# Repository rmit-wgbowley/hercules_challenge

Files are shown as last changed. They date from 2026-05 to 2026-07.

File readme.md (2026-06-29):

<!--
Color Palette:
- #F3F4F4
- #0DFDF7
-->

<p align="center">
  
  <br>
  <em>Axial Shake Powered Pill System – Electromechanical Design of the IsoPod by <a href="https://github.com/wgbowley">William Bowley</a></em>
</p>

--- 
The Hercules Challenge is a co-design consortium challenge available to first-semester, first-year engineers through the mandatory introductory class, "Introduction to Professional Engineering."

> [!IMPORTANT]
> `The Pantheon` consortium received a commendation award for their work on the `IsoPod` at the Hercules Challenge night at RMIT.

---

TLDR: Designed, simulated, manufactured, and experimentally validated a human-powered axial electromagnetic generator producing `0.43–0.47 W` from hand shaking using custom FEA and physical prototype testing

# Overview






The `IsoPod` is a pill system that reminds users when to take their medication through an e-ink display on the cylindrical face of the device, providing a simple visual reminder.

This repository focuses on the design, simulation, construction, and validation of the `axial shake generator` (ASG) at the device's core. The generator converts intentional shaking motion into electrical energy via magnetic induction, which charges the IsoPod's Li-Po battery. This extends battery life, or with enough motion, can enable complete self-reliance.

> [!Important]
> **Measured Output (8.8 Hz human shaking):**
> - Peak Voltage: `16.8 V`
> - RMS Voltage: `3.47 V`
> - Power Output: `0.43–0.47 W`

> [!Important]
> The generator has not been tested with a charging load nor power management system. Power output is expected to decrease, but the magnitude is unknown.

### Why generate electrical?

In humanitarian contexts, reliable grid power isn't guaranteed, nor are reliable supply chains for expendable batteries. The ASG decouples the `IsoPod` from external infrastructure by converting user motion into electrical 
energy.

### Table of Contents

- [Overview](#overview)
- [Why generate electrical?](#why-generate-electrical)
- [Axial Shake Generator](#axial-shake-generator)
  - [Electromagnetics](#electromagnetics)
  - [Design & Topology](#design--topology)
  - [Numerical Model](#numerical-model)
  - [Simulation Results](#simulation-results)
- [Construction](#construction)
- [Results](#results)
- [Validation](#validation)
  - [New Mechanical Model](#new-mechanical-model)
  - [Simulation Results](#simulation-results-1)
- [Conclusion](#conclusion)
- [Bibtex Citation](#bibtex-citation)

# Axial Shake Generator

<div align="center">
  <a href="02_fabrication/readme.md">
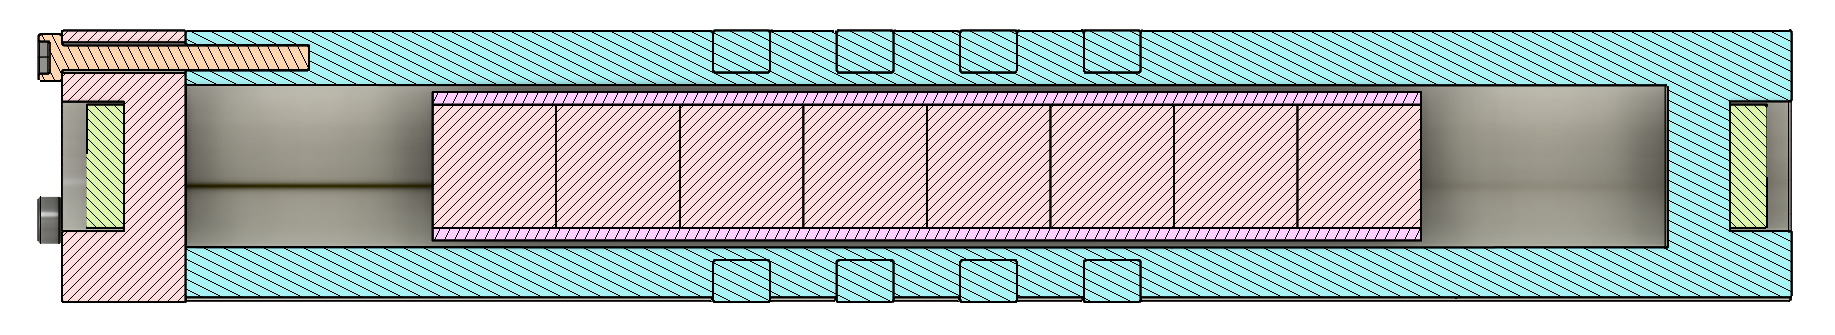
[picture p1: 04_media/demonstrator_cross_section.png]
Generator cross section
    
  </a>
  <p><i>Figure 1: Cross-sectional analysis: <a href="02_fabrication/readme.md">Click here for CAD files</a></i></p>
</div>

The generator consists of an armature `(greyish-olive)` made of poles (magnets), a stator `(minty aqua)` made of slots (coils), and restoring magnets `(light yellow-green)` which act as magnetic springs that allow the armature to build velocity from the user shaking the device with their forearm muscles.

## Electromagnetics

An ASG produces electricity via the interaction between a slot and a pole. When a pole moves axially through a slot, it produces an induced voltage within that slot due to the changing magnetic field generating a changing electric field. The induced electric field opposes the change in magnetic flux that produced it, a consequence of Lenz's law. These ideas come together to form `Faraday's Law of Induction`:

$$V = -N\frac{d\Phi}{dt} \implies -\frac{d\lambda}{dt}$$

where $λ = N\Phi$ is the flux linkage between the slot and pole. Flux linkage can be thought of as the magnitude of how strongly the magnetic field links with the winding (turns in a slot). Higher linkage generally means the system can produce a larger induced voltage for the same change in armature position.

Luckily, using related rates, the two main parameters appear:

$$V_{\text{induced}} = -\frac{d\lambda}{dt} \implies -\frac{d\lambda}{dz} \cdot \frac{dz}{dt}$$

The first term is the derivative of flux linkage over the z-axis (magnetic design), and the second term is the z-axis velocity (mechanical input). These can be analytically approximated as:

> [!important]
> Flux linkage can be approximated analytically for intuition. The final flux linkage was obtained using Finite Element Analysis (FEA).

$$\frac{dz}{dt} = A \omega \cos(\omega t + \phi)$$
$$\frac{d\lambda}{dz} = \frac{d}{dz} (B \cos(kz)) \implies -\mu H k \sin(kz)$$

> [!note]
> For a simple magnetic circuit, magnetic flux density can be related to magnetic field strength by `B = μH`, where `B` is the magnetic flux density, `H` is the magnetic field intensity, and `μ` is the permeability, the ability of a material to support magnetic flux.

where `k = 2π / pitch` is the spatial frequency.

These two derivatives expose the important mechanics of the system. Increasing acceleration `A` and frequency `ω` may increase induced voltage, but these are constrained by the user's physical abilities. Whereas the permeability `μ` and `H` may increase the induced voltage while generally not being constrained by the user's physical abilities.

Once induced voltage is established, the usable electrical power is determined by the generator's internal resistance:

$$P = \frac{V_{\text{rms}}^2}{R_{\text{internal}}}$$

This relationship drives one of the main trade-offs: increasing turns raises induced voltage but also increases resistance due to longer wire length. The optimal design maximizes `V/R`, not just peak voltage.

> [!important]
> The generator design was constrained by the IsoPod system requirements:
> - Cylindrical form factor: radial thickness < `12.5 mm`, height < `250 mm`
> - Human-powered input motion (reasonable frequency and acceleration)
> - Low-maintenance energy harvesting
> - Easy to construct with basic tools

## Design & Topology

<div align="center">
  Generator high-level topology
  <p><i>Figure 2: High level electrical machine topology</i></p>
</div>

> [!note]
> `N-S` represents an axially magnetized permanent magnet pole. `PA` represents phase A, where `PA+` and `PA-` indicate opposite winding directions.

The high-level topology in figure 2 was selected to enable oscillatory motion through magnetic restoring forces. The end poles act as magnetic springs, creating a restoring force when the armature approaches the limits of travel.

The alternating pole arrangement (`N-S|S-N`) was selected because the transition between opposing poles creates a rapid change in magnetic field along the z-axis, increasing the spatial rate of change of flux linkage:

$$V \propto \frac{d\lambda}{dz}$$

A pole pitch of `10 mm` was selected, matching the pole length and maintaining direct magnetic coupling between adjacent opposing poles. The topology uses four stator slots interacting with four active armature poles, with two additional poles placed on each end of the armature to increase usable travel distance. This allows approximately `20 mm` of positive and negative armature displacement while maintaining magnetic coupling between the armature and stator.

Maintaining slot overlap throughout the motion range produces a more consistent induced voltage waveform, where the primary amplitude is dominated by the mechanical velocity term:

$$V \propto \frac{dz}{dt}$$

The symmetric pole arrangement also reduces unwanted harmonic content compared with asymmetric topologies. Finally, no high-permeability materials were introduced into the armature or stator structure. The stator consists of copper windings, while the magnetic poles use `N52 Neodymium` permanent magnets.

Given the 4 slots within the stator and the 8 poles within the armature, the measured frequency relationship suggests:

$$f_{\text{electrical}} \approx 4 \times f_{\text{mechanical}}$$

This is consistent with the pole pitch and the number of magnetic cycles encountered per mechanical oscillation.

## Numerical Model

> [!important]
> This area is recommended for individuals more familiar with electromagnetic finite element simulations.

The ASG was modelled using `FemmMagneticRender` (FEMM) with `shapely` for translating `PYFEA` CSG (constructive solid geometry) to FEMM native primitives. An axially symmetric coordinate system (z-r) was used due to the generator's rotational symmetry around its z-axis. A Dirichlet boundary condition was applied, with the radial boundary at `2×` the slot outer radius and the axial boundary at `1.2×` the stator tube length. The armature motion relative to the origin was simulated using:

$$ z = \text{travel} \cdot \sin(2\pi f t) $$

The resistance was obtained from `FemmMagneticSolver` during an initial configuration solve, and then the flux linkage was obtained per solve. Using the simulation time-step, the induced voltage was calculated using finite difference:

$$V_{\text{induced}} = -\frac{\lambda_{\text{new}} - \lambda_{\text{old}}}{t_{\text{step}}}$$

This was then used to calculate the RMS voltage, and using the generator's internal resistance, the expected power output was obtained. This method represents a `quasi-transient` method due to its use of asymptotic field conditions ($t=\infty$) per time step. This is reasonable due to the absence of highly magnetically permeable materials and the low operating frequency of the generator.

## Simulation Results

> [!IMPORTANT]
> The model was configured with the following parameters:
> - Temperature: `293.15 K`, Time step: `1ms`
> - Mechanical Shaking Frequency: `8.81 Hz`, Electrical Shaking Frequency: `35.2 Hz`
> - peak-to-peak travel: `40 mm`
> - Pole Coercivity: `956 kA/m`, Pole Permeability: `1.05 ∅`
> - Slot Conductivity: `60.07 MS/m`, Slot Permeability: `1.0 ∅`, Fill Factor: `0.47 ∅`, Turns: `184`

<div align="center">
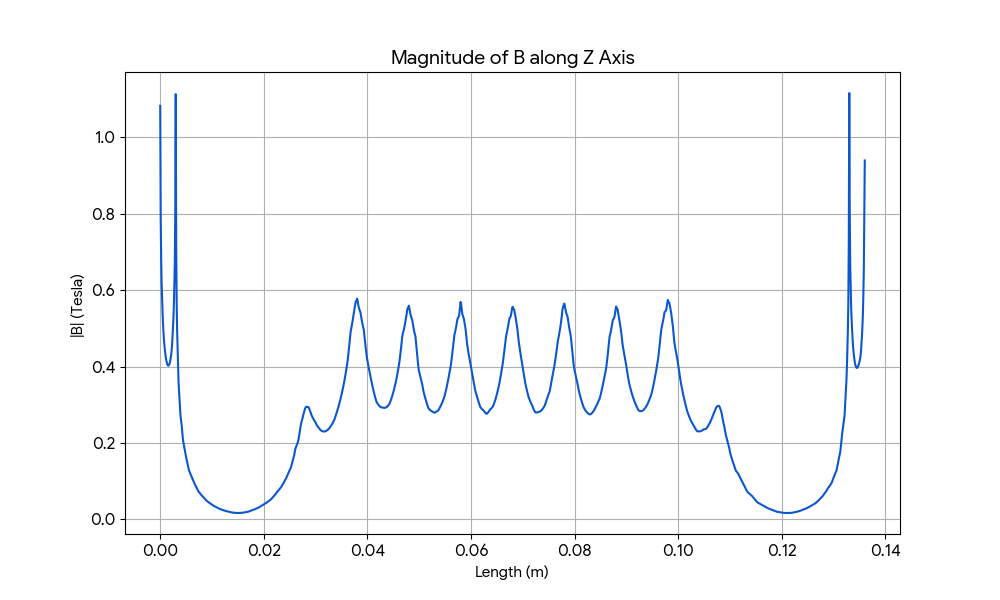
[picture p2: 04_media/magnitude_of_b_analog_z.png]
|B| vs Z
  
  <p><i>Figure 3: Simulated static |B| along the z-axis of the generator</i></p>
</div>

> [!IMPORTANT]
> The quasi-transient simulation predicted:
> - Time: `0.228 s`, Time steps: `228`
> - Peak voltage: `5.161 V`, RMS Voltage: `2.696 V` 
> - Positive Rate: `486.06 V/s`, Negative Rate: `-844.25 V/s`
> - Resistance: `22.54 Ω`, Power: `0.323 W` 

<div align="center">
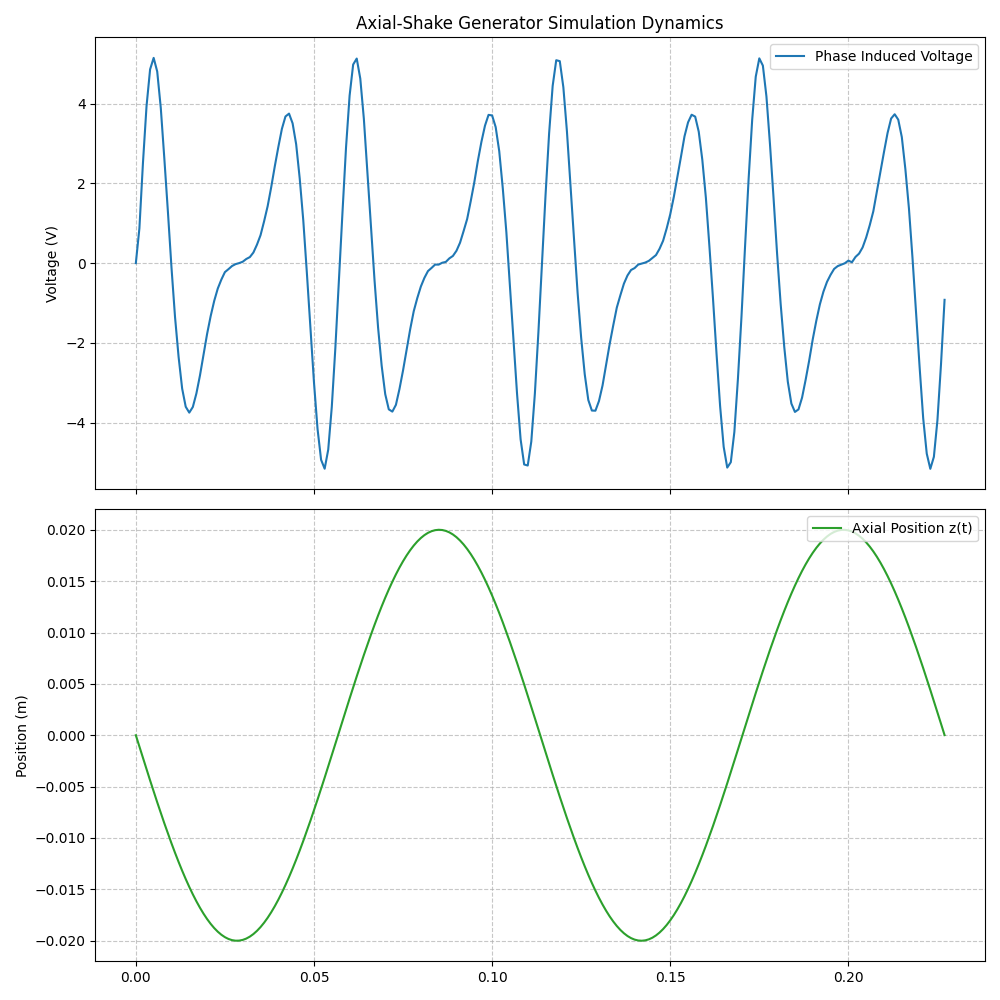
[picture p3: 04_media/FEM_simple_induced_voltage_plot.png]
Induced voltage vs time
  
  <p><i>Figure 4: Simulated induced voltage vs time and position vs time</i></p>
</div>

The parameter file can be found [here](01_simulation/01_simple_motion/parameters.uiv), written in `.uiv` (unit-informed values). The simulation files can be found [here](01_simulation/readme.md), written in Python using the `pyfea` solver-adapter engine. Solver assumptions can be found [here](03_data/assumptions_printout.md).

## Construction

The generator was printed out of ABS on a Voron 2.4. The armature consisted of a carbon fibre rod with `8` x `N52` poles inserted into it in the pattern described above, using superglue to secure the end poles.

The stator consisted of `4` coils with `180` turns per coil of `0.2 mm` enameled copper wire, with each coil wound in the opposite direction to the last as described above. The coils were secured in place with `10 mm` and `5 mm` thick Kapton tape, with the first and last layers of the coil being wrapped.

The restoring magnets were flat `12 mm x 3 mm` neodymium magnets. The generator stator was split into two pieces: the main piece, which housed the coils and one restoring magnet, and the cap, which held the other restoring magnet and was attached via `3` x `M3 x 20 mm` bolts. The two outputs of the generator were secured to the side and then extended with `~1.25 mm` stranded copper wire.

<div align="center">
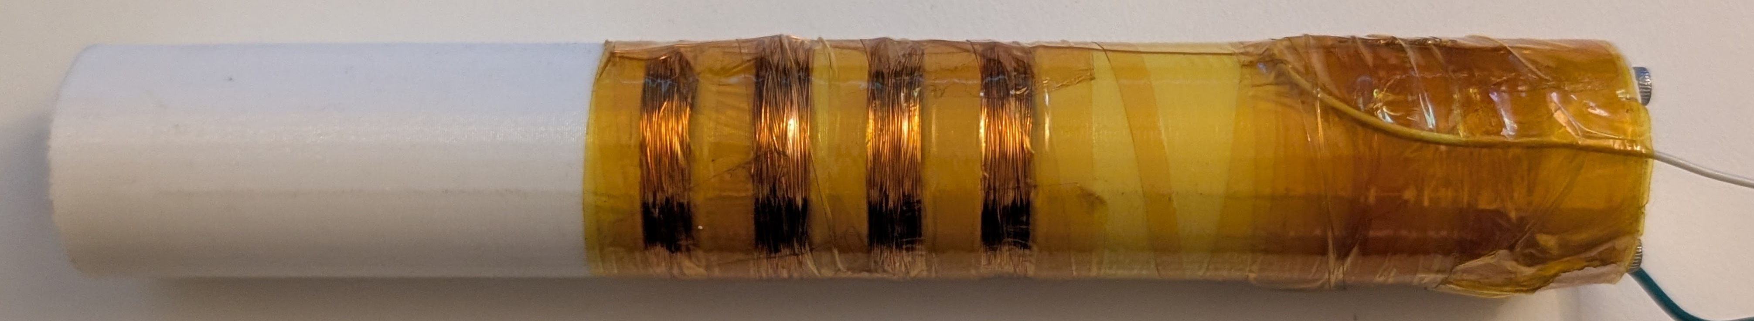
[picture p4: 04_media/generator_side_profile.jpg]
Generator Side profile
  
  <p><i>Figure 5: Side profile (Construction)</i></p>
</div>

## Results

The completed generator was tested by hand-shaking at a measured fundamental mechanical frequency of `8.81 Hz` with an electrical frequency of `35.2 Hz`
(the 4 coils produce 4 cycles per mechanical oscillation). The open-circuit voltage was recorded using an oscilloscope:

> [!IMPORTANT]
> The oscilloscope measurements:
> - Positive Peak: `16.8 V`, Negative Peak: `-16.4 V`
> - Positive Rate: `131 V/s`, Negative Rate: `-246 V/s` (Slew Rate)
> - V_RMS(AV): `3.47 V`, V_RMS(PEAK): `3.63 V`
> - Resistance: `27.8 Ω`, Power: `0.43-0.47 W`

> [!NOTE]
> Slew rate can be affected by probe loading due to parasitic capacitance and inductance. Hence `dv/dt` may be slowed due to the `RLC` circuit formed.

<div align="center">
  Oscilloscope trace
  <p><i>Figure 6: Voltage vs time trace @ 10V/div vertical, 50ms/div horizontal</i></p>
</div>

The measured waveform shown in Figure 6 has a similar shape to the predicted waveform in Figure 4 but seems less periodic and more jerky. Another observation is that the negative recovery appears stretched while still being a similar amplitude. This is most likely attributed to degradation of the prototype due to its usage as a demo item.

# Validation

The simulated power output was `0.323 W` whereas the measured power was `0.43-0.47 W`, which is `25-45%` lower than the measured value. The peak voltages are much higher and the slew rate was significantly different, leading to the possible source being the idealized motion of the armature versus the realized motion.

The simulation used the same mechanical frequency but produced lower peak voltages. If the prototype's armature acceleration was much higher than expected, the armature was likely slamming into the end-caps due to the repulsion force not being high enough. The maximum velocity was most likely higher and hence:

$$V \propto \frac{d\lambda}{dz}$$

## New Mechanical Model

> [!important]
> This area is recommended for individuals more familiar with electromagnetic finite element simulations.

Given this, a new model for the motion could be proposed that takes into consideration the magnetic repulsion force and the likely much higher mechanical acceleration but lower frequency, using an oscillating force function:

$$F_{\text{magnetic}} = -\frac{dU}{dz}$$
$$F_{\text{shaking}} = am\sin(\omega t + \phi)$$

One approach would be to model the armature velocity as:

$$\frac{dz}{dt} = \int \frac{F_{\text{magnetic}} + F_{\text{shaking}}}{m} \ dt$$

> [!Note]
> Euler method was used to integrate from acceleration to z-position, the stability was not formalized.

However, given the ability of `FemmMagneticSolver` to calculate the Maxwell stress tensor, the $F_{\text{magnetic}}$ term was obtained directly from the solver rather than using finite difference of the magnetic energy density over the z-axis. This decouples the solution from the displacement output, removing dynamic step sizes and leading to a potentially more stable solution.

## Simulation Results 

> [!IMPORTANT]
> The model was configured with the following parameters:
> - Temperature: `293.15 K`, Time step: `1 ms`
> - Mechanical Shaking Frequency: `8.8 Hz`, Electrical Shaking Frequency: `35.2 Hz`
> - Acceleration: `100 m/s²`, peak-to-peak travel: `40 mm`
> - Pole Coercivity: `956 kA/m`, Pole Permeability: `1.05 ∅`
> - Slot Conductivity: `60.07 MS/m`, Slot Permeability: `1.0 ∅`, Fill Factor: `0.47 ∅`, Turns: `184`

> [!IMPORTANT]
> The quasi-transient simulation predicted:
> - Time: `0.228 s`, Time steps: `228`
> - Peak voltage: `12.35 V`, RMS Voltage: `3.44 V` 
> - Positive Rate: `634.76 V/s`, Negative Rate: `-2.32 kV/s`
> - Resistance: `22.54 Ω`, Power: `0.526 W` 

<div align="center">
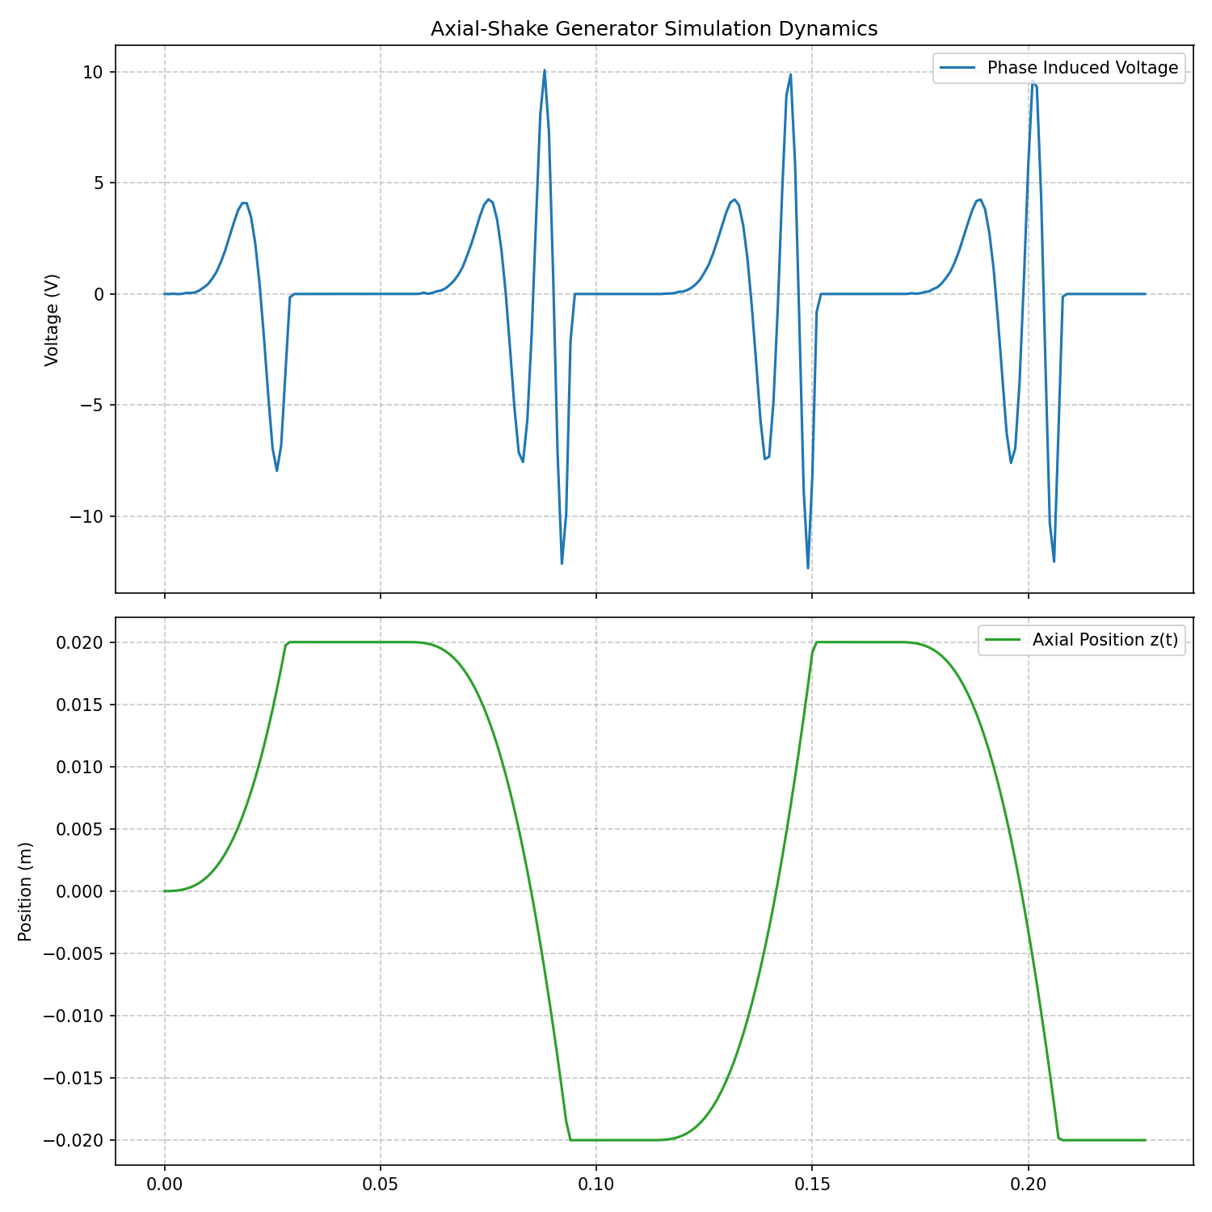
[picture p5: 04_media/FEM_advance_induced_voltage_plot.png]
Induced voltage vs time
  
  <p><i>Figure 7: New simulation results (Simulation Results)</i></p>
</div>

The parameter file can be found [here](01_simulation/02_advance_motion/parameters.uiv), written in `.uiv` (unit-informed values). The simulation files can be found [here](01_simulation/readme.md), written in Python using the `pyfea` solver-adapter engine. Solver assumptions can be found [here](03_data/assumptions_printout.md).

# Conclusion

The axial shake generator successfully produced `0.43-0.47 W` of usable power from human motion at a mechanical frequency of `8.8 Hz` (electrical `35.2 Hz`) with an unknown acceleration function. The simulation with the new mechanical model predicted `0.526 W`, within `12-22%` of measured values. The differences in slew rates between the simulation and measured results can be attributed to no-load electrical dynamics versus the oscilloscope probe loading.

> [!IMPORTANT]
> Key Takeaways:
> - The `N-S|S-N` magnet topology effectively increases `dλ/dz`, producing sharp B-field spikes
> - The mechanical model incorporating boundary clamping and Maxwell stress tensor produces a waveform shape much closer to reality than the ideal sinusoidal model
> - The quasi-transient model using a hybrid force function predicted power within `22%`; however, acceleration needs validation
> - The `180` turn prototype produced `16.8 V` peaks, which is sufficient for the IsoPod's target applications

> [!TIP]
> Future work should focus on:
> - Using a shaking apparatus for repeatable external motion paths that could be fed into the simulation
> - Improving fill factor to decrease generator size or increase the number of turns within the generator's form factor
> - Validating the computational model across more generator parameters and pole-slot factors
> - Investigating whether the end-cap magnets improve energy output or reduce it
> - Investigating efficient methods of converting electrical energy into stored energy
> - Investigating the effect of the probe's `RLC` circuit or generator conversion circuit on dynamics

The generator design demonstrated the feasibility of powering low-energy devices in humanitarian contexts where grid power is unreliable, depending on load factors. However, it may be more viable as a battery supplementary system, depending on the trade-offs between battery size and generator duty cycle.

### Bibtex Citation:

```
@misc{Bowley_2024,
  author = {Bowley, William},
  title = {{IsoPod: Axial Shake Generator}},
  url = {https://github.com/rmit-wgbowley/isopod-generator},
  year = {2024},
  note = {
    GitHub repository,
    Electromagnetic Subsystem Of The Isopod
  },
  license = {MIT}
}
```

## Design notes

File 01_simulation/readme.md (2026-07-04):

# Simulation

> [!WARNING]
> pyFEA is functionally working and produces physically consistent results.
> However, the API and abstraction boundaries are still under active development and may change.
> It is not yet stable as a public-facing dependency.

## 01 Simple Motion

A reduced-order motion model used to approximate armature dynamics while minimising computational cost.
This model assumes a simplified prescribed motion profile for the moving armature.

### Limitation
Validation against prototype measurements showed a 25–45% underprediction in power output.  
This discrepancy is attributed to the assumed motion profile not capturing the armature's true dynamics.

Simple motion can be found [here](/01_simulation/01_simple_motion/).

## 02 Advanced Motion

This simulation uses a prescribed oscillatory motion model combined with Maxwell stress tensor-based force computation 
to evaluate electromagnetic forces (`F_magnetic`) acting on the armature.

The magnetic force is computed directly from the field solution, avoiding energy-difference approximations.

### Limitation
Validation against prototype measurements showed results within 12–22% of measured values.

Advanced motion can be found [here](/01_simulation/02_advance_motion/).

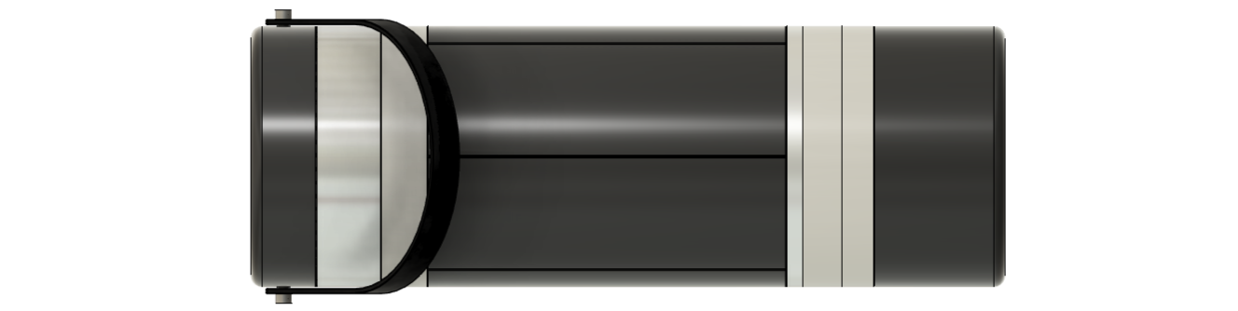
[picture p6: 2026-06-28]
04_media/isopod_model.png

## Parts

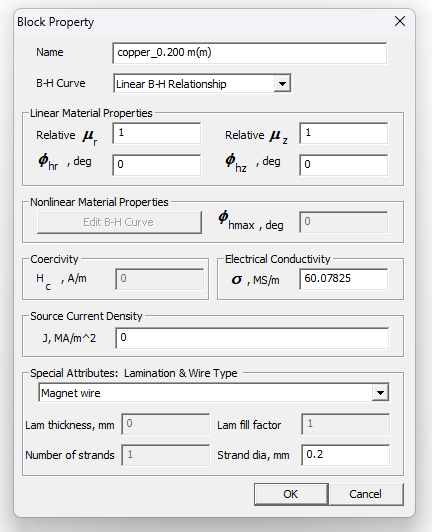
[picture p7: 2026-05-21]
04_media/FEM_copper_material.png

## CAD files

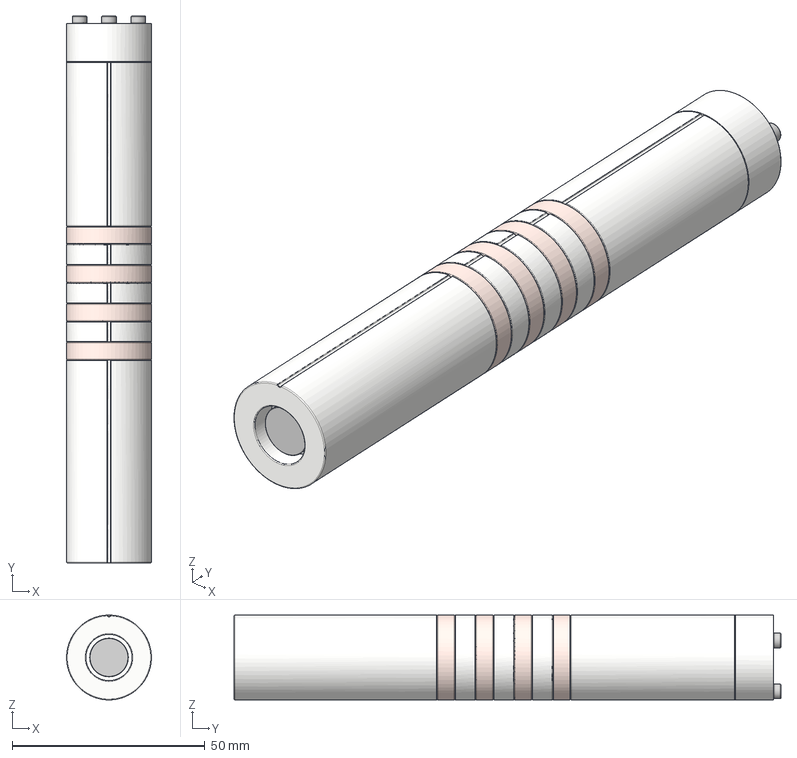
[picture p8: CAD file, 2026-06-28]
02_fabrication/axial_generator.iges
22.0 x 141.9 x 22.0 mm

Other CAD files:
02_fabrication/axial_generator.f3z

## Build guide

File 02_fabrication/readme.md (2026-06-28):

# Simple BOM

> [!IMPORTANT]
> **Armature (Moving Part):**
> - 8 × N52 magnets (10 mm diameter × 10 mm axial length)
> - 80 mm carbon fibre tube (10 mm inner diameter × 12 mm outer diameter)
> - Superglue (to secure end magnets)
>
> **Stator (Stationary Part):**
> - 2 × N52 restoring magnets (12 mm diameter × 3 mm axial length)
> - 0.2 mm enameled copper wire (~2-5 m)
> - ABS or PLA filament (for 3D printed housing)
> - 3 × M3 × 20 mm bolts (to secure stator cap)
>
> **Tools:**
> - 3D printer (Voron 2.4 or similar)
> - Oscilloscope (for testing)

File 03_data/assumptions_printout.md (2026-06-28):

# Solver Assumptions

> [!Important]
> Solver Adapter: FEMMMagnetostaticSolver
> These assumptions apply to both the initial resistance solution and each quasi-transient frame.

```
=== model assumptions ===
• Coordinates = axi, depth = 0.000 (m)
• Frequency = 0 Hz, asymptotic field conditions
• Dirichlet Boundary (A = 0), Flux boundary shunt
• copper_0.200 m(m) coercivity assumed to be 0.0 (A/m)
• copper_0.200 m(m) uses linear interpolation to calculate conductivity
• Phase is assumed to be a constant current source
• NdFeB uses linear interpolation to calculate conductivity
• Air coercivity assumed to be 0.0 (A/m)
• Air uses linear interpolation to calculate conductivity
• Air conductivity set to 0.0 (S/m) to ensure correct domain behavior (gases only)
=========================
```

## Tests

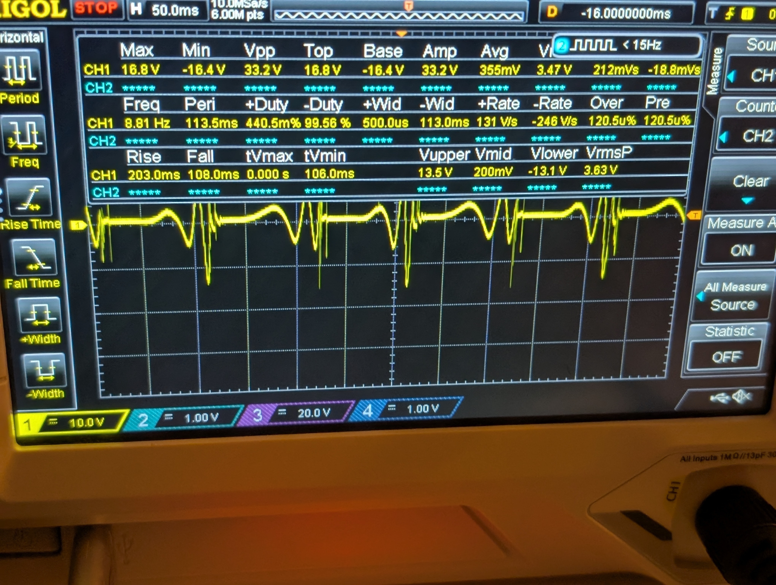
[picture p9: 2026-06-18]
04_media/oscilloscope_measurements_on_trace.jpg

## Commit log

2026-05-24 WIP: IR Bisector PCB
    [ir_bisector.kicad_pcb, ir_bisector.kicad_sch]
2026-05-24 sensor board finished
    [ir_bisector.kicad_pcb, ir_bisector.kicad_sch, ir_board.step]
2026-06-01 Moving submission prototype into proposal_submission
    [ir_bisector.kicad_pcb, ir_bisector.kicad_sch, ir_board.step]
2026-06-07 resonant frequency model for springs
2026-06-12 rework before deliverable prototype for competition night
    [demonstrator_generator.iges]
2026-06-16 Updates to readme & descoping deliverable pcb
2026-06-28 Merge development into main for release (#10)
    * Quick Save -> Reorganization
    * adding images & data
    * new folder/file structure based on 01,02,...,n
    * Create readme.md
    * Look of the new start of the readme within the repo
    * what about with power in it like that?
    * okay hows that?
    * correction
    * check + add side profile image.
    * introduction
    * test with electromagnetic section
    * finished electromagnetics area
    * few fixes
    * test
    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
    [axial_generator.f3z, axial_generator.iges, demonstrator_generator.iges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]

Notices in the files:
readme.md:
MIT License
